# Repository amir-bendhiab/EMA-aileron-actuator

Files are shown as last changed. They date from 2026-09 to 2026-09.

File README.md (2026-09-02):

EMA — Actionneur Électromécanique pour Gouverne d'Aileron

Projet portfolio personnel : conception complète d'un actionneur électromécanique (EMA), du cahier des charges jusqu'à l'électronique embarquée — référence d'application : gouverne d'aileron de Pilatus PC-12.

<!-- Ajoutez ici une image de couverture : rendu CAO, ou photo du montage si prototype physique -->
🎯 Contexte

Ce projet couvre le cycle de conception complet d'un actionneur électromécanique linéaire destiné à piloter une gouverne d'aileron : cahier des charges, conception mécanique, modélisation dynamique, commande en boucle fermée, validation par simulation, et conception de l'électronique embarquée.

📐 Spécifications clés
Paramètre	Valeur
Moteur	DC 24V / 300W (ATO-D5BLD300)
Réducteur	Rapport 5:1
Vis à billes	SFU1605
Course	±34,2 mm
Butées mécaniques (linéaire)	±37 mm
Débattement angulaire (gouverne)	+25° / −15° (40° total)
Modèle de charge aérodynamique	T_aero = k·θ (k nominal = 11,73 N·m/deg)
🗂️ Avancement du projet
 Phase 0 — Cahier des charges
 Phase 1 — Conception CAO (SolidWorks)
 Phase 2 — Modélisation électromécanique (Simscape)
 Phase 3 — Commande PID en cascade (courant → vitesse → angle)
 Phase 4 — Validation en simulation
 Phase 5 — Électronique + microcontrôleur (schéma + PCB KiCad)
 Phase 6 — Prototype physique (optionnelle, non prévue dans le cadre de ce projet)
 Phase 7 — Documentation finale (en cours)
🔧 Détail des phases
Phases 1-2 — CAO & Modélisation
Capture d'écran 2026-09-02 200703

Conception mécanique complète sous SolidWorks, puis modélisation électromécanique du système sous Simscape (MATLAB/Simulink) pour disposer d'un modèle dynamique fidèle avant de synthétiser la commande.

Phase 1 (révision) — Butée mécanique angulaire
<!-- Ajoutez ici une capture de la liaison d'angle avec limites dans SolidWorks -->

Après validation de la commande en simulation (Phase 4), retour sur la CAO pour traduire la plage validée en contrainte mécanique cohérente : une liaison d'angle avec limites (+25° / −15°) sur l'axe de charnière — seul élément de la chaîne cinématique dont la rotation reste fixe dans l'espace, donc le seul candidat pertinent pour une butée directe.

La chaîne cinématique complète a été reconstruite et validée dans SolidWorks avec les liaisons mécaniques appropriées : liaison Pignon (couplage rigide réducteur → vis à billes via l'accouplement) et liaison Vis (conversion rotation → translation, pas de 5mm) pour la vis à billes. Une seconde liaison d'angle, en marge de sécurité, protège le bras de levier contre les configurations géométriques non réalistes (le bras combinant rotation et translation, sans butée physique propre dans la réalité).

Phase 3 — Commande
Capture d'écran 2026-09-02 201233

Architecture de commande en cascade à trois boucles imbriquées : courant → vitesse → angle, chacune réglée successivement de l'intérieur vers l'extérieur.

Phase 4 — Validation en simulation

Tests par échelons (+25° / −15°) face à un modèle de charge aérodynamique. Un point notable du processus : la limitation de courant initiale (±5A) empêchait l'actionneur d'atteindre l'angle cible en butée de saturation — corrigée à ±12A après vérification du courant nominal réel du moteur. Un test de robustesse complémentaire (doublement de la raideur de charge aérodynamique k) a confirmé la tenue du système face à une charge plus sévère que le cas nominal.

Phase 5 — Électronique (schéma + PCB)
Capture d'écran 2026-09-02 200900
Capture d'écran 2026-09-02 200851

Conception complète sous KiCad :

Alimentation : 28V → 5V (LM2596S) → 3,3V (AMS1117), régulation à deux étages
Driver moteur : BTS7960 (pont en H)
Mesure de courant : INA240 + shunt 0,01Ω, dimensionné pour ~14A avec marge de sécurité
Retour de position : encodeur magnétique absolu AS5048A (interface SPI)
Microcontrôleur : STM32F401RETx

Schéma validé (ERC : 0 erreur). PCB 120×80mm entièrement routé et validé (DRC : 0 violation, 0 connexion manquante), avec 5 zones de cuivre dédiées à la puissance (+28V, GND double face, retour moteur).

Limitation connue : les pistes de puissance sont restées à la largeur standard (0,25mm) plutôt que la largeur calculée pour ~14A (8mm), documentée directement sur le PCB. Choix assumé : ce PCB est un exercice de conception, non destiné à la fabrication physique dans le cadre de ce projet.

🛠️ Stack technique
CAO : SolidWorks
Simulation & Commande : MATLAB/Simulink, Simscape
Électronique : KiCad
Microcontrôleur cible : STM32F401RETx
🚀 Suite du projet
Développement du firmware embarqué (implémentation temps réel de la boucle de commande sur STM32)
Documentation finale consolidée
👤 À propos

Projet réalisé par Amir Ben Dhiab, étudiant ingénieur en Génie Électromécanique (spécialisation Robotique & IA) à l'École Polytechnique de Sousse (EPS), Tunisie — dans le cadre de la préparation aux candidatures de stage de fin d'études (PFE), février 2027.

🔗 github.com/amir-bendhiab

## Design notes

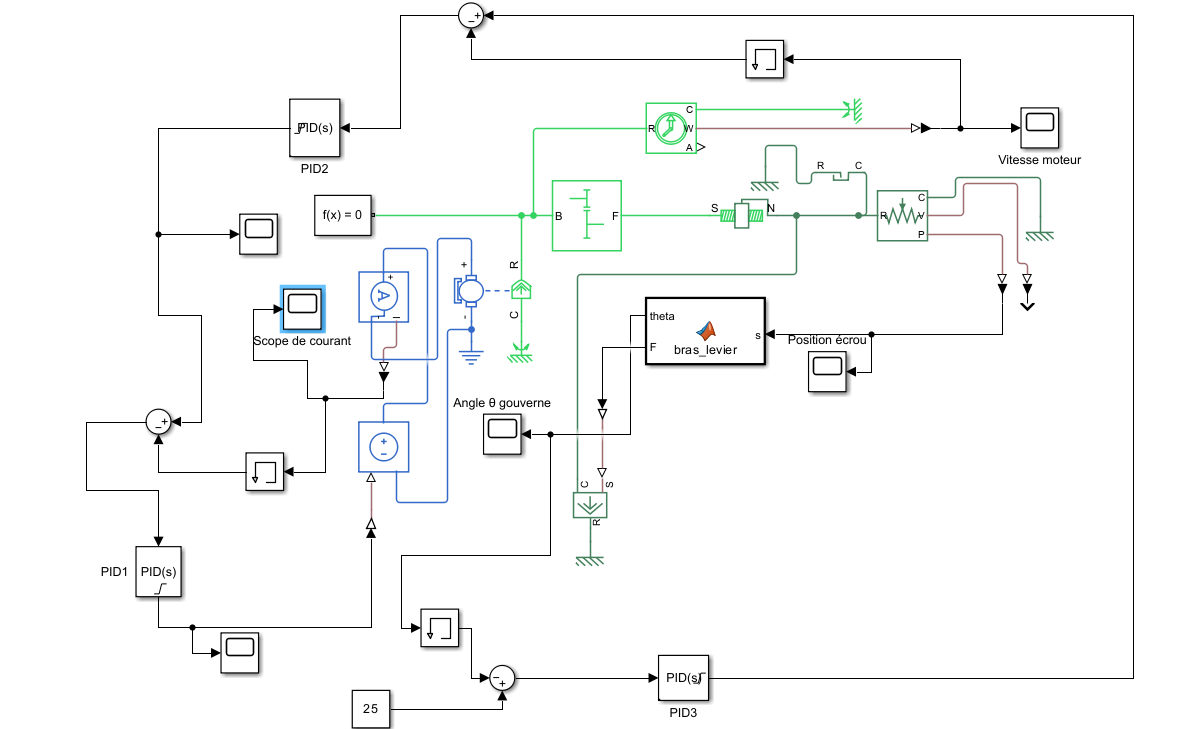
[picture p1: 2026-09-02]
02-Simscape/capture simulink.png

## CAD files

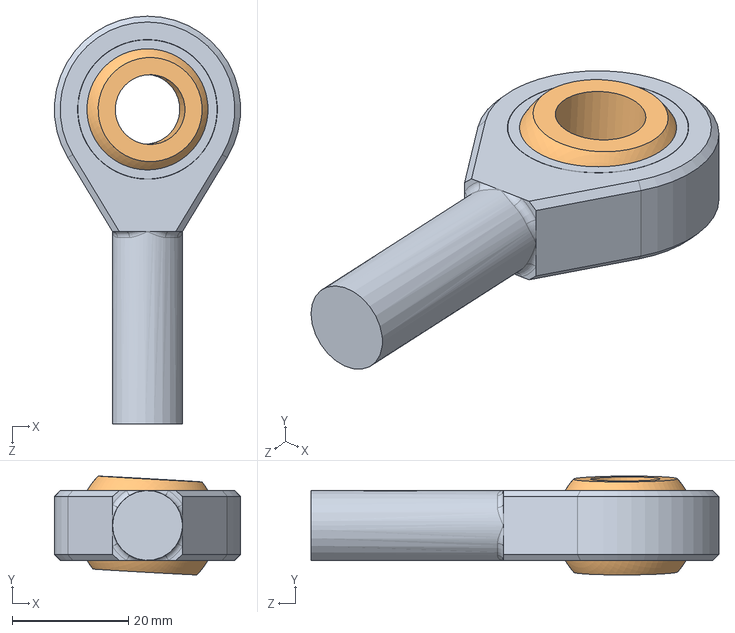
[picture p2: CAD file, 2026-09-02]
01-CAO-SolidWorks/M12 ROD END WORKING.SLDASM
31.9 x 17.0 x 70.0 mm
M12ROD END
ROD END BALL

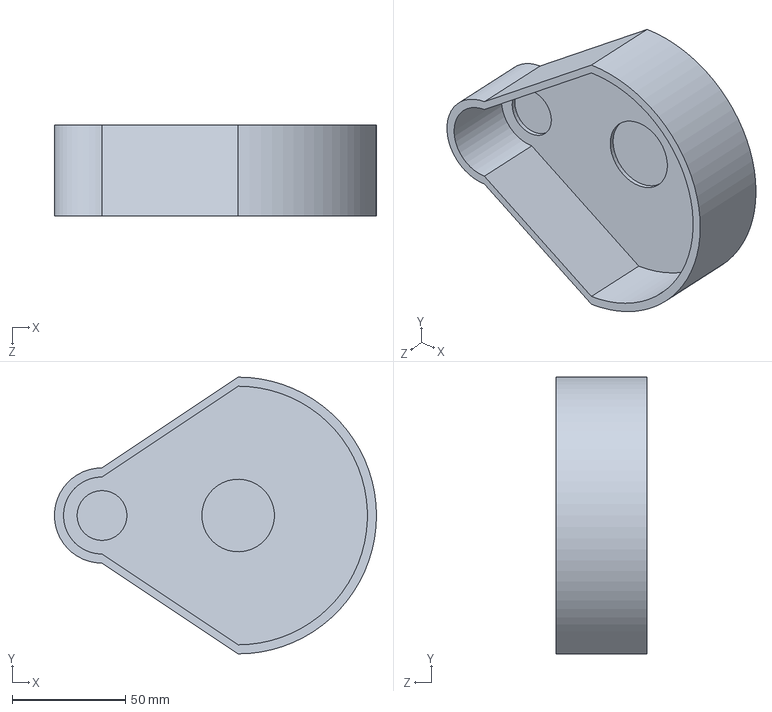
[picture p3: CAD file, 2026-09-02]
01-CAO-SolidWorks/carter.SLDPRT
142.0 x 122.0 x 40.0 mm

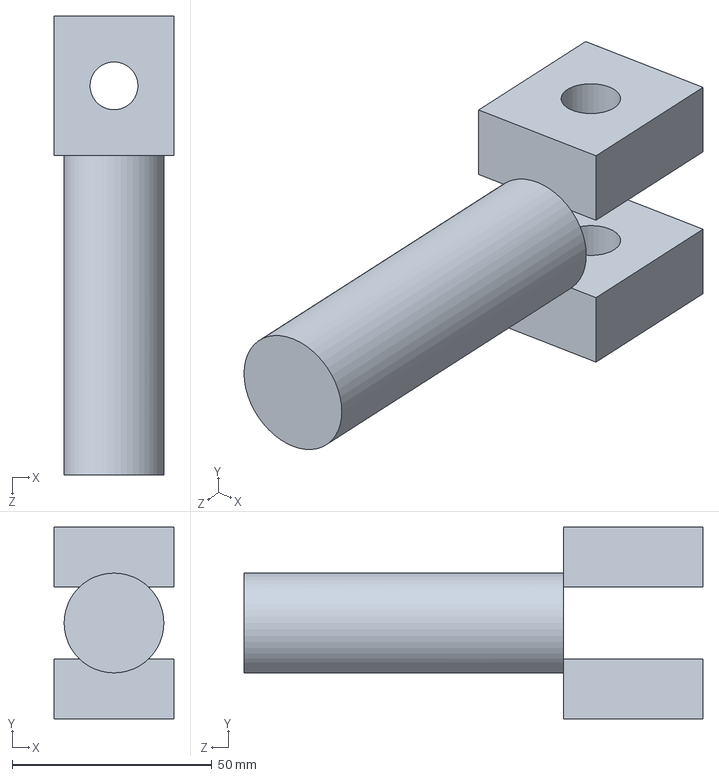
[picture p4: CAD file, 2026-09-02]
01-CAO-SolidWorks/Axe_Charniere_Gouverne.SLDPRT
30.0 x 48.0 x 115.0 mm

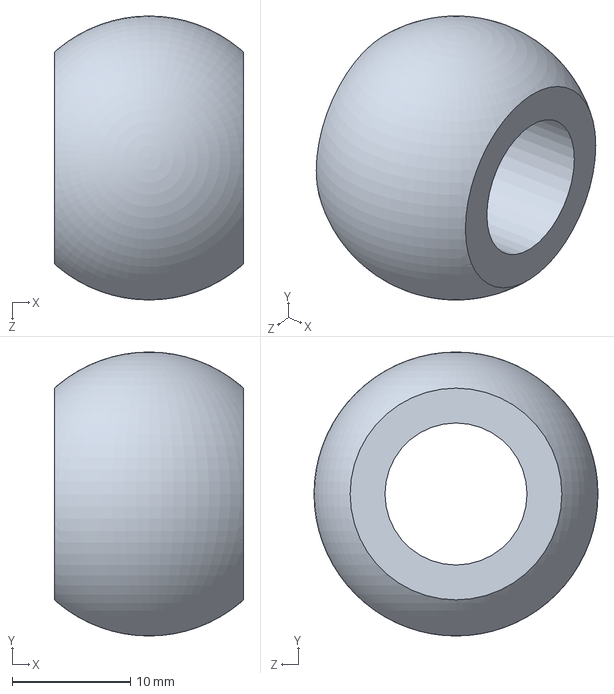
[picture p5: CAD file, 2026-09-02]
01-CAO-SolidWorks/ROD END BALL.SLDPRT
16.0 x 24.0 x 24.0 mm

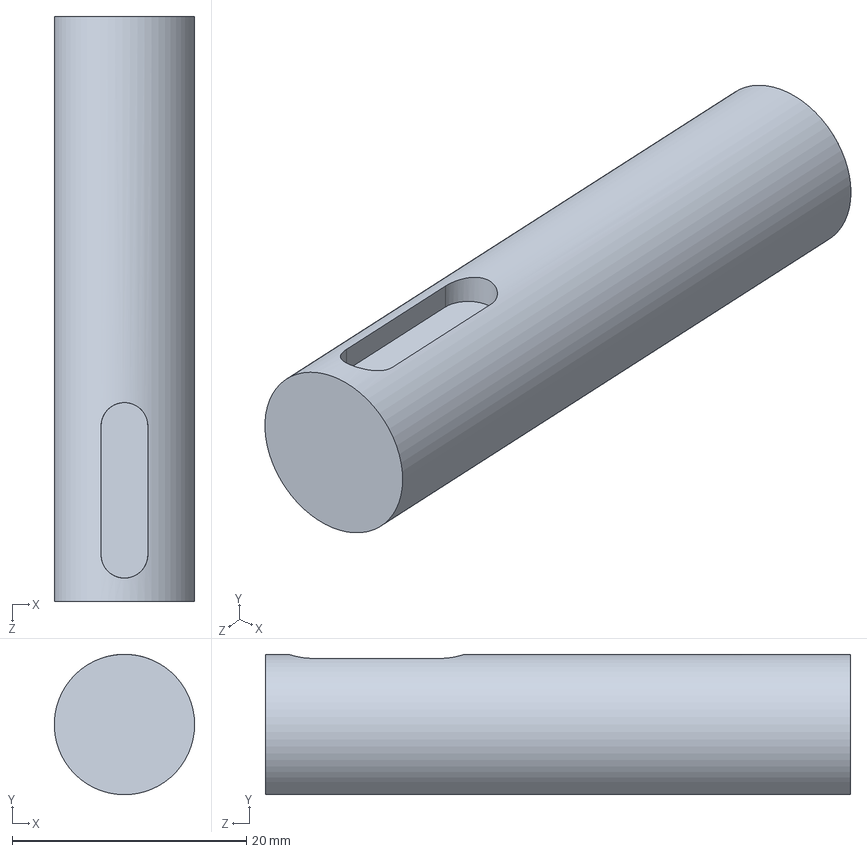
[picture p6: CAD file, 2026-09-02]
01-CAO-SolidWorks/arbre de sortie avec clavetage.SLDPRT
12.0 x 12.0 x 50.0 mm

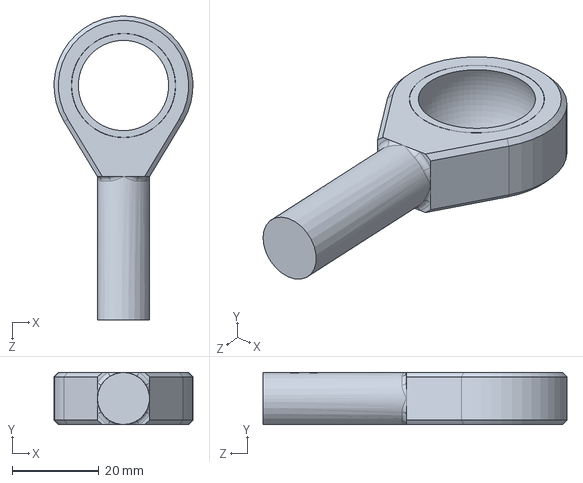
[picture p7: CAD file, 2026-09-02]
01-CAO-SolidWorks/M12ROD END.SLDPRT
31.9 x 12.0 x 70.0 mm

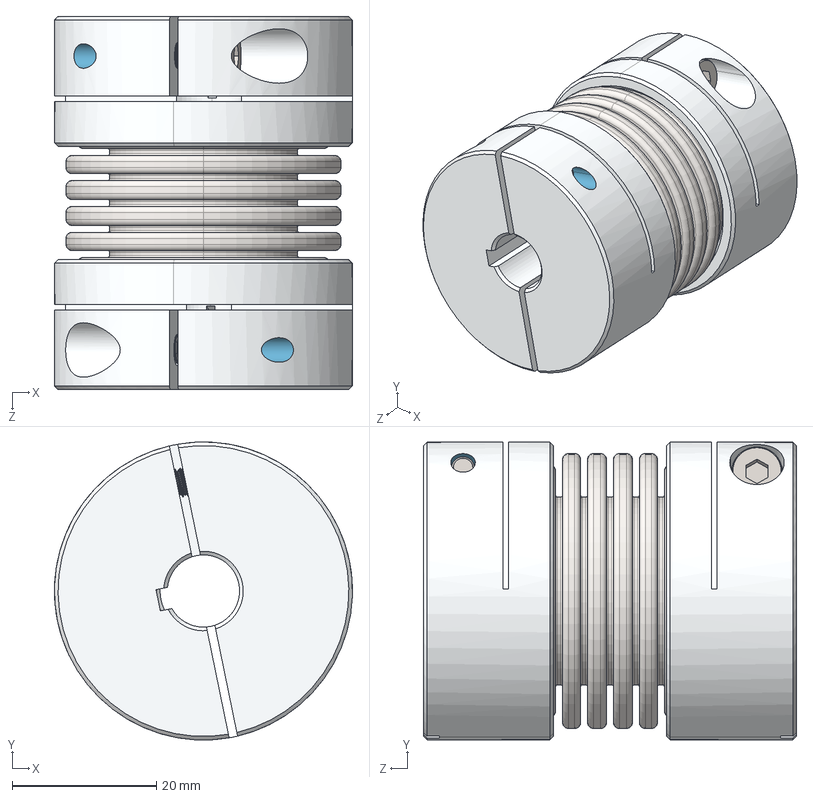
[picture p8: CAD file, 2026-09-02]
01-CAO-SolidWorks/Ruland_MBCK41-12-10-A.step
41.3 x 41.2 x 51.7 mm
MBCCH41-x_MBCCH41-12
Metric Socket Head Cap Screws 1C_CFM4_14 x 2
MBCCH41-x_MBCCH41-10
Bellows26&41-4_New 2022 Bellows

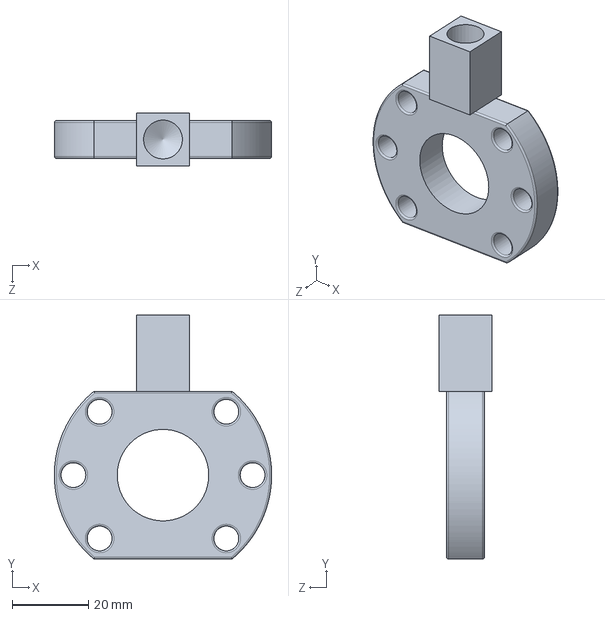
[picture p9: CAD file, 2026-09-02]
01-CAO-SolidWorks/BRIDE ECROU 2.SLDPRT
57.0 x 64.0 x 14.0 mm

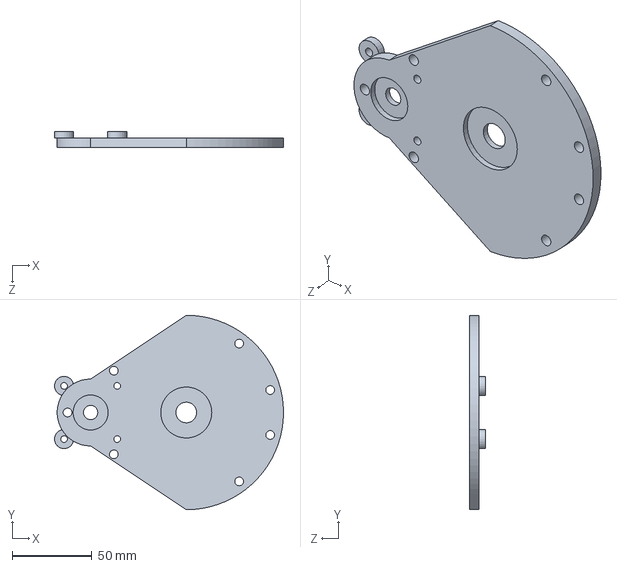
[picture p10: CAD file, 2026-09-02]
01-CAO-SolidWorks/capuchon.SLDPRT
143.7 x 122.0 x 10.0 mm

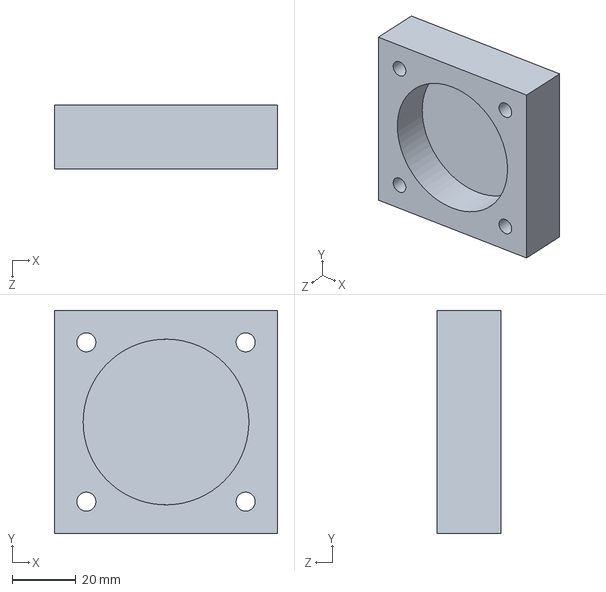
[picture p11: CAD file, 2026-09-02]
01-CAO-SolidWorks/Support_Palier_Gouverne.SLDPRT..SLDPRT
70.0 x 70.0 x 20.0 mm

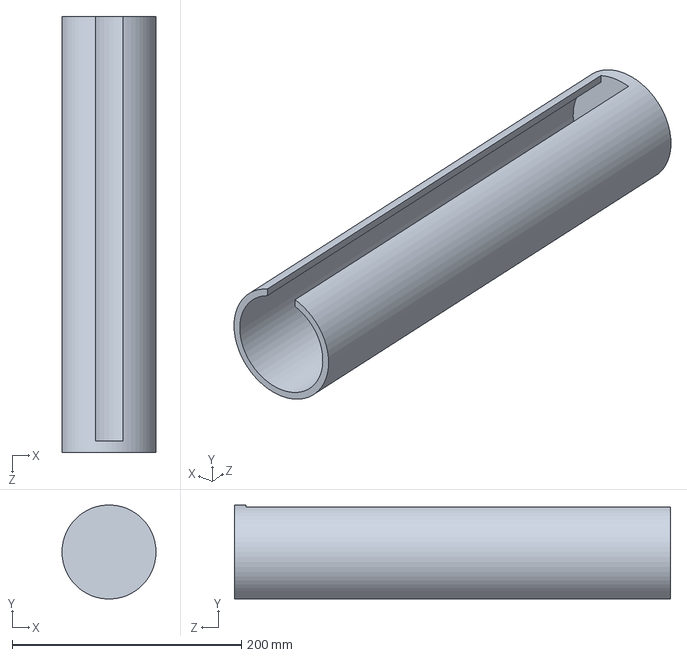
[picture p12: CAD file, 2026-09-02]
01-CAO-SolidWorks/Tube_Boitier_Actionneur.SLDPRT
82.0 x 81.9 x 380.0 mm

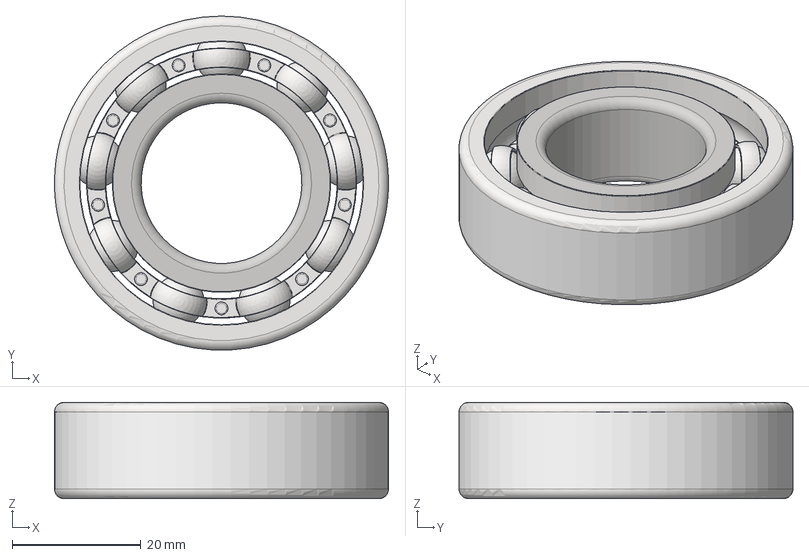
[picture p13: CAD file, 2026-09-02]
01-CAO-SolidWorks/6205.stp
52.0 x 52.0 x 15.0 mm
Inner Race
Outer Race
Ball x 9
Cage x 2
Rivit x 9

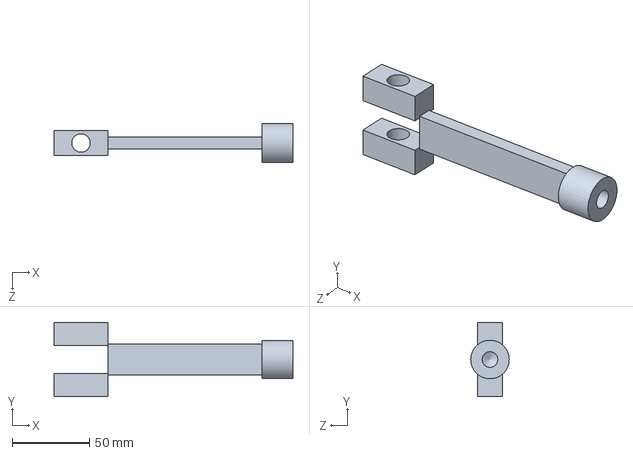
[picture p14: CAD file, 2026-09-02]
01-CAO-SolidWorks/Bras_Levier.SLDPRT
155.0 x 48.0 x 25.0 mm

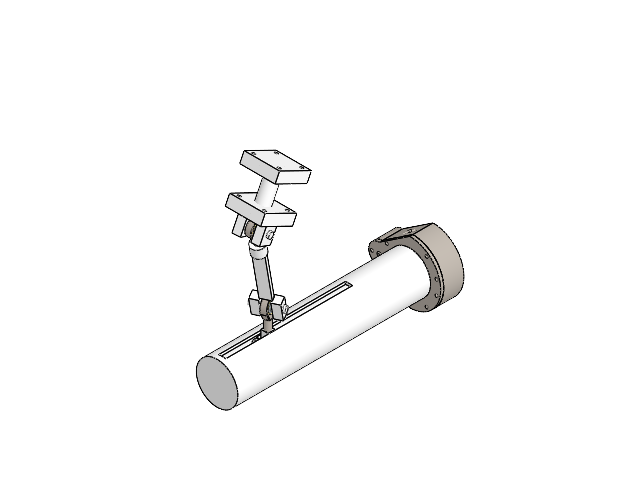
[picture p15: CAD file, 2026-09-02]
01-CAO-SolidWorks/EMA-Aileron-actuator.SLDASM
carter
radial ball bearing_68_iso
spur gear_iso x 2
radial ball bearing_68_riso x 2
arbre de sortie avec clavetage
capuchon
M12ROD END x 2
ROD END BALL x 2
Bras_Levier
cylindre x 2
MBCCH41-x_MBCCH41-12_1.step
Metric Socket Head Cap Screws 1C_CFM4_14_1.step x 2
MBCCH41-x_MBCCH41-10_1.step
Bellows26&41-4_New 2022 Bellows_1.step
Axe_Charniere_Gouverne
Inner Race_1.stp x 2
Outer Race_1.stp x 2
Ball_1.stp x 18
Cage_1.stp x 4
Rivit_1.stp x 18
Support_Palier_Gouverne.SLDPRT. x 2
Tube_Boitier_Actionneur
BRIDE ECROU 2
Generic Ballscrew
Generic Nut

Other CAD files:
01-CAO-SolidWorks/roue_100dents.SLDASM
01-CAO-SolidWorks/roulement6201.SLDASM
01-CAO-SolidWorks/pignon_20dents.SLDASM
01-CAO-SolidWorks/roulement_moteur.SLDASM
01-CAO-SolidWorks/Generic Ballscrew.SLDPRT
01-CAO-SolidWorks/Generic Nut.SLDPRT
01-CAO-SolidWorks/cylindre.SLDPRT

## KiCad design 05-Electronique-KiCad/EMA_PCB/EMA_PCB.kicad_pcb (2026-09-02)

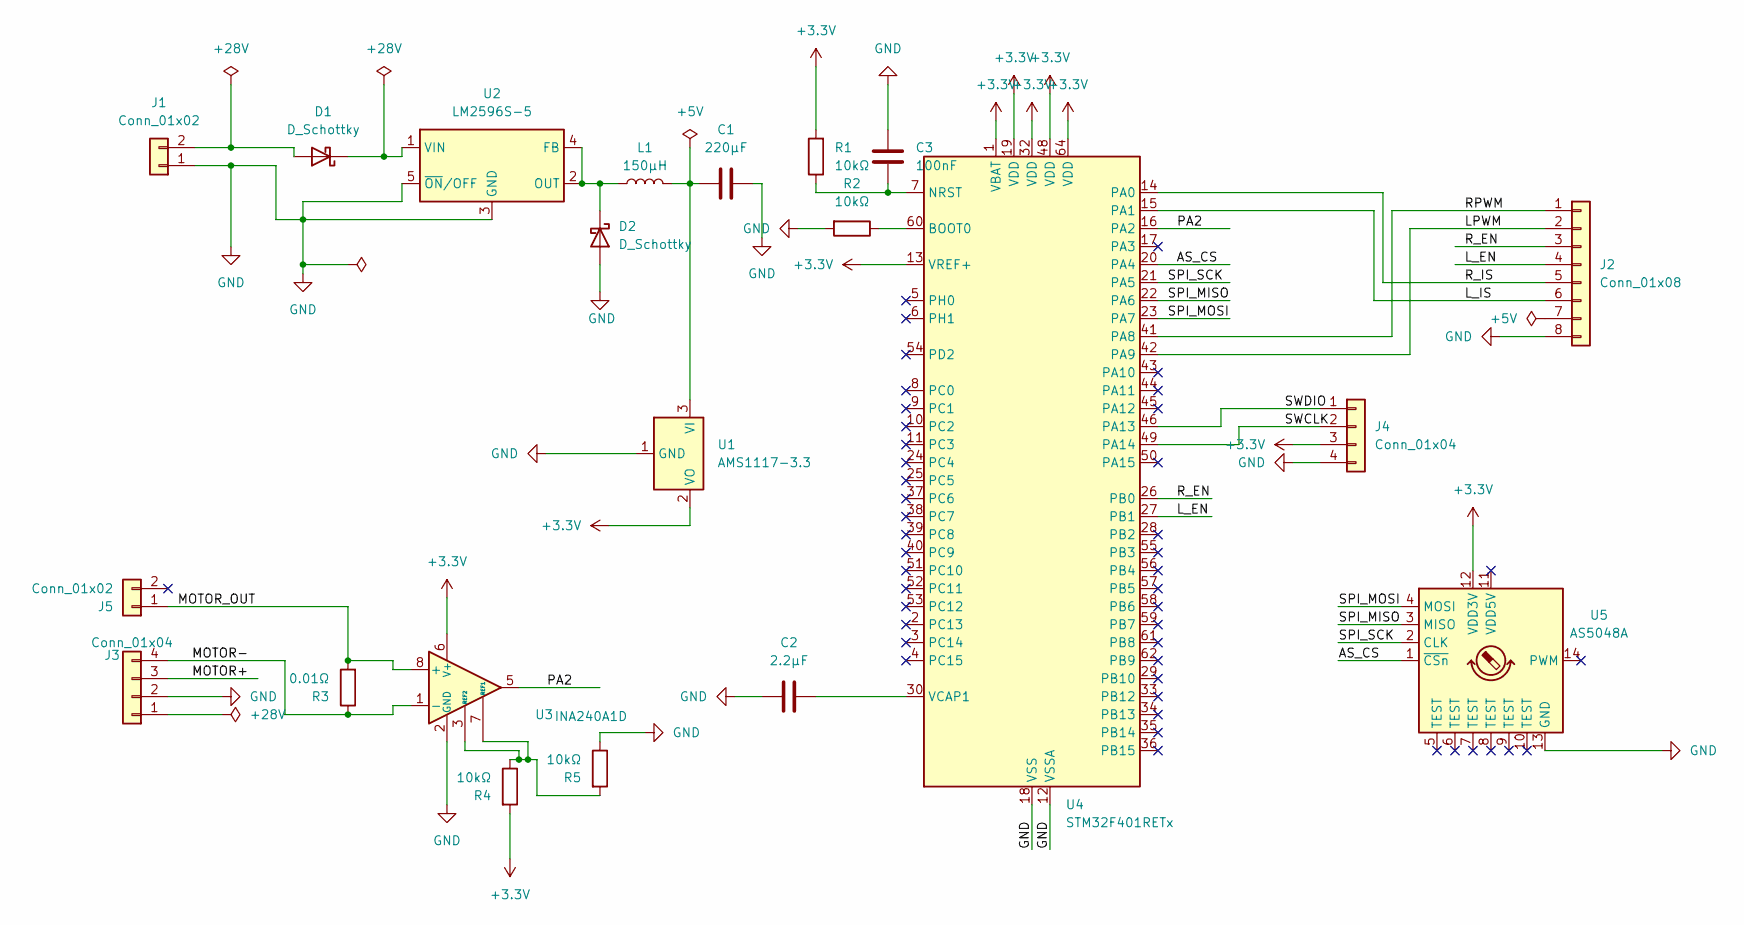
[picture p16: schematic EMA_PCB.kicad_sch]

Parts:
C1: 220µF; CP_Radial_D8.0mm_P3.50mm
C2: 2.2µF; C_0805_2012Metric
C3: 100nF; C_0603_1608Metric
D1, D2: D_Schottky; D_SMA
J1, J5: Conn_01x02; TerminalBlock_CUI_TB007-508-02_1x02_P5.08mm_Horizontal
J2: Conn_01x08; PinHeader_1x08_P2.54mm_Vertical
J3: Conn_01x04; TerminalBlock_CUI_TB007-508-04_1x04_P5.08mm_Horizontal
J4: Conn_01x04; PinHeader_1x04_P2.54mm_Vertical
L1: 150µH; L_Wuerth_WE-TPC-3816
R1, R2, R4, R5: 10kΩ; R_0805_2012Metric
R3: 0.01Ω; R_2512_6332Metric
U1: AMS1117-3.3; SOT-223-3_TabPin2
U2: LM2596S-5; TO-263-5_TabPin3
U3: INA240A1D; SOIC-8_3.9x4.9mm_P1.27mm
U4: STM32F401RETx; LQFP-64_10x10mm_P0.5mm
U5: AS5048A; TSSOP-14_4.4x5mm_P0.65mm

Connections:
+3.3V: J4.3, R1.2, R4.2, U1.2 (VO), U3.6 (V+), U4.1 (VBAT), U4.13 (VREF+), U4.19 (VDD), U4.32 (VDD), U4.48 (VDD), U4.64 (VDD), U5.12 (VDD3V)
/AS_CS: U4.20 (PA4), U5.1 (~CSn)
/LPWM: J2.2, U4.42 (PA9)
/L_EN: J2.4, U4.27 (PB1)
/L_IS: J2.6, U4.15 (PA1)
/MOTOR+: J3.3
/MOTOR-: J3.4, R3.1, U3.1 (-)
/MOTOR_OUT: J5.1 (Pin_1_1), R3.2, U3.8 (+)
/PA2: U3.5, U4.16 (PA2)
/RPWM: J2.1, U4.41 (PA8)
/R_EN: J2.3, U4.26 (PB0)
/R_IS: J2.5, U4.14 (PA0)
/SPI_MISO: U4.22 (PA6), U5.3 (MISO)
/SPI_MOSI: U4.23 (PA7), U5.4 (MOSI)
/SPI_SCK: U4.21 (PA5), U5.2 (CLK)
/SWCLK: J4.2, U4.49 (PA14)
/SWDIO: J4.1, U4.46 (PA13)
GND: C1.2, C2.1, C3.2, D2.2 (A), J1.1, J2.8, J3.2, J4.4, R2.2, R5.1, U1.1 (GND), U2.3 (GND), U2.5 (~ON/OFF), U3.2 (GND), U3.4 (GND), U4.12 (VSSA), U4.18 (VSS), U4.31 (VSS), U4.47 (VSS), U4.63 (VSS), U5.13 (GND)
unnamed: D1.2 (A), J1.2
unnamed: D1.1 (K), U2.1 (VIN)
unnamed: D2.1 (K), L1.1, U2.2 (OUT), U2.4 (FB)
unnamed: C1.1, L1.2, U1.3 (VI)
unnamed: R4.1, R5.2, U3.3 (REF2), U3.7 (REF1)
unnamed: R2.1, U4.60 (BOOT0)
unnamed: C3.1, R1.1, U4.7 (NRST)
unnamed: C2.2, U4.30 (VCAP1)

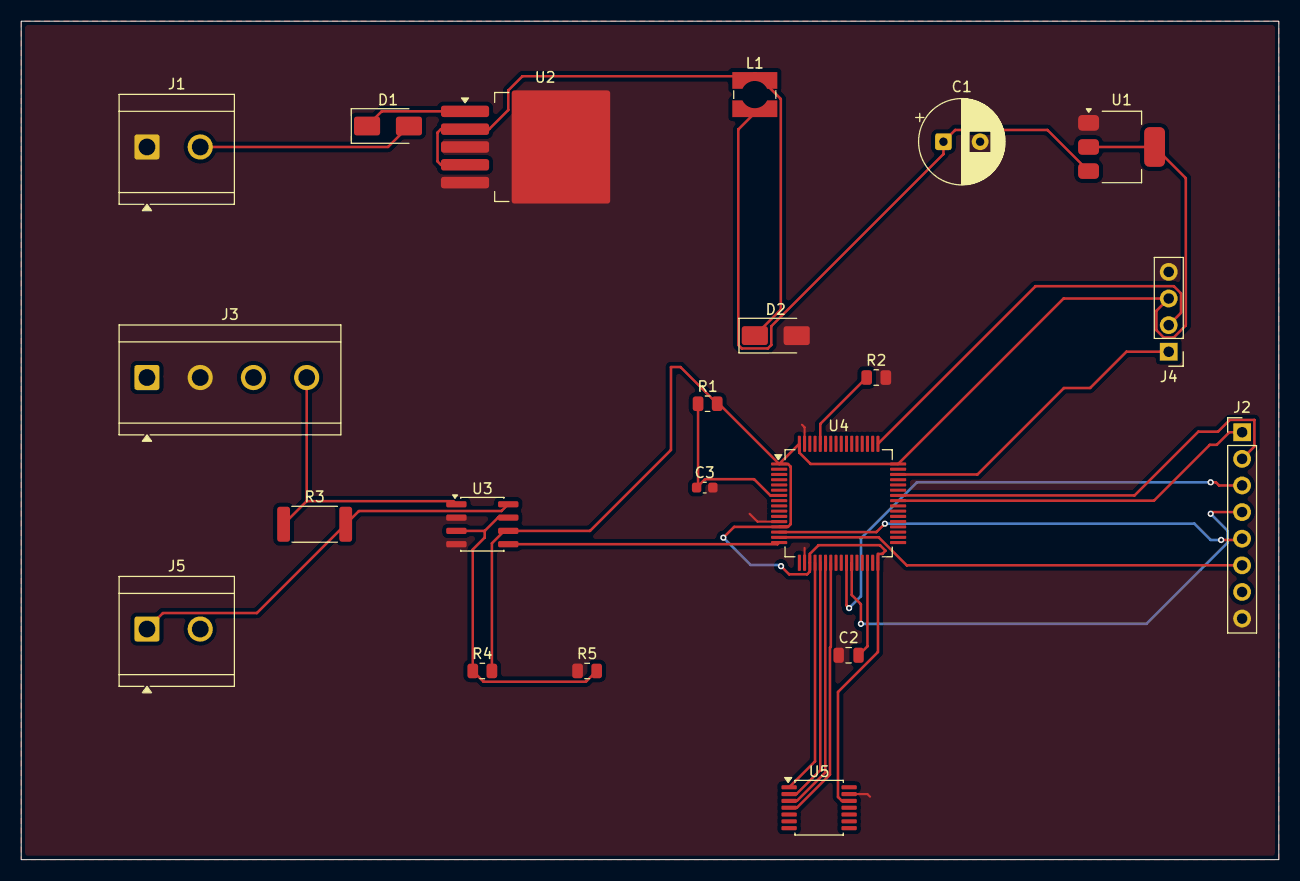
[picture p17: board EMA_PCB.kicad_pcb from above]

Board: 2 copper layers, 120.0 x 80.0 mm, 21 parts (0 on the bottom side), 25 nets.

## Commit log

2026-09-02 Ajout du modèle 3D (STL) et des pièces CAO complètes
    [6205.stp, Axe_Charniere_Gouverne.SLDPRT, BRIDE ECROU 2.SLDPRT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]
2026-09-02 Correction export STL en fichier unique
    [REDUCTEUR - 6205.stp-1 Ball_1.stp-18.STL, REDUCTEUR - 6205.stp-1 Ball_1.stp-19.STL, REDUCTEUR - 6205.stp-1 Ball_1.stp-20.STL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]
